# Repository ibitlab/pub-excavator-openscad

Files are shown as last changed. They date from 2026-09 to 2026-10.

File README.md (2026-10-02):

**English** · [Українська](README.uk.md)

<picture>
  <source media="(prefers-color-scheme: dark)" srcset="docs/logo/ibitlab-logo-dark.svg">
  ibitlab
</picture>

# Mini excavator boom, stick and bucket — a parametric OpenSCAD model

> ⚠️ **Ihor Ivaniuk (@IBITLAB) is the originator and product owner: organises the AI's work, sets the tasks, makes the decisions. The execution — geometry, calculations, drawings, code and texts — is done by AI (Claude Code by Anthropic).** Not checked by an engineer, never built, never tested. A mini excavator can maim and kill; everything here is provided as is, at your own risk. The full disclaimer is [below](#disclaimer); the hazards specific to this design are in [SAFETY.md](SAFETY.md). Read both before you cut any metal.

## ▶ [Open the live 3D model](https://ibitlab.github.io/pub-excavator-openscad/)

**[ibitlab.github.io/pub-excavator-openscad](https://ibitlab.github.io/pub-excavator-openscad/)** — nothing to install: OpenSCAD runs inside the page (WebAssembly). Move the boom, stick and bucket or simply drag the bucket with the mouse, switch on the work envelope and the "what is welded to what" colouring, change any parameter of the model — it is rebuilt right in the browser. Works on a phone too.

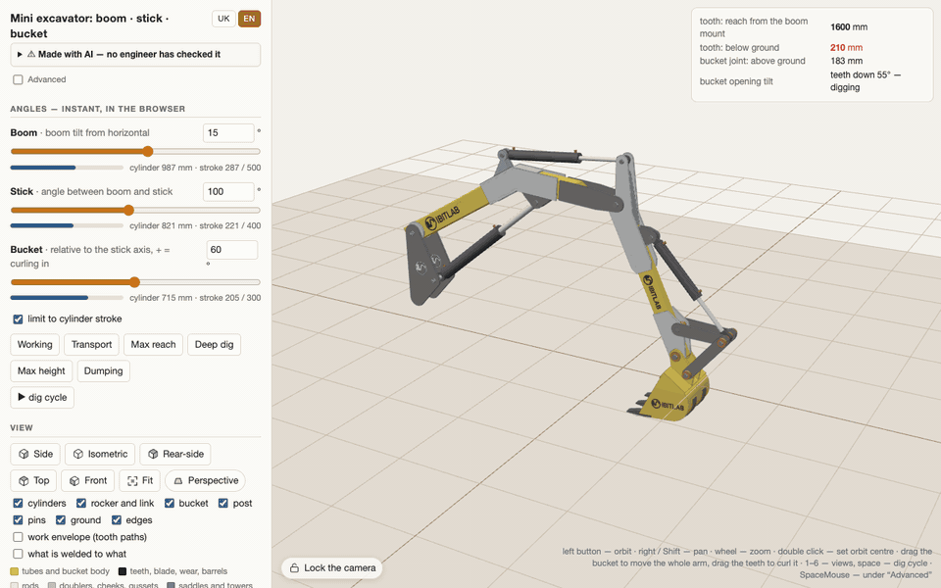
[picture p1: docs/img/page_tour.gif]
A tour of the 3D page: the dig cycle, the work envelope, the extreme poses, what is welded to what (https://ibitlab.github.io/pub-excavator-openscad/)


**AR at 1:1.** On an Android phone with Chrome the same page puts the machine on the ground through the camera, at full size; the sliders move the boom, stick and bucket exactly as on screen (clip sped up 4×). How it works: [web/README.md](web/README.md).

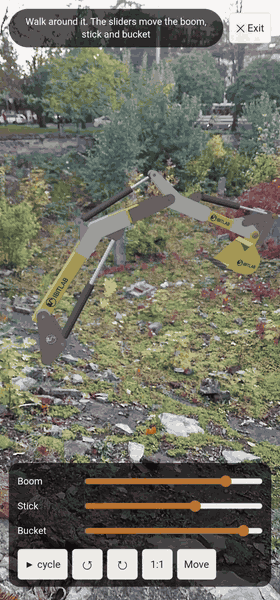
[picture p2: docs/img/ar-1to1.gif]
The excavator in AR at 1:1 on a patch of ground, sliders moving the boom, stick and bucket


## Documents (PDF, in Ukrainian)

**[Part sketches in steel](latest/drawings/parts.pdf)** — the bill of materials, every plate with its hole positions tied to real edges, the tubes unfolded on all four sides; the logo is marked where the decal goes. For cutting: DXF 1:1 in [`dxf/`](latest/dxf/).

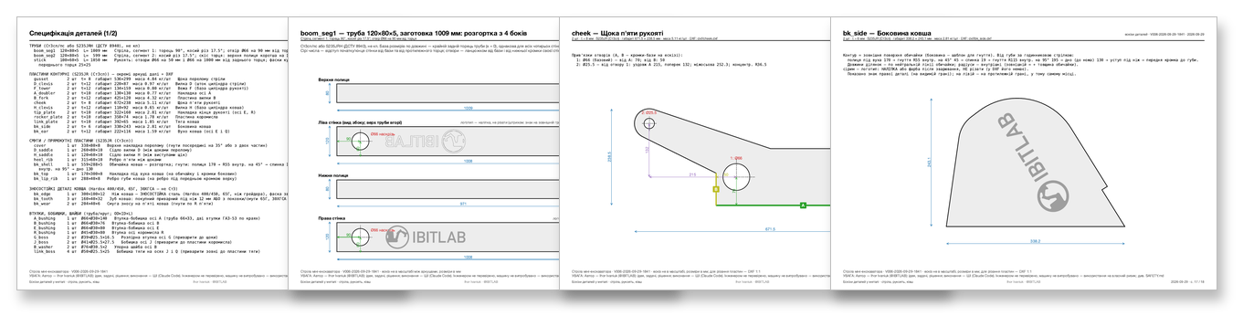
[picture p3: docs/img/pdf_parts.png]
Part sketches in steel


**[1:1 sorting sheets for the 1:5 printed kit](latest/print3d/sheets/SHEETS.pdf)** — every printed part drawn at 1:1 the way it lies on the table: put the part on its outline, and if it fits, that is the one; renders of each sub-assembly with a callout to every file, then gluing step cards.

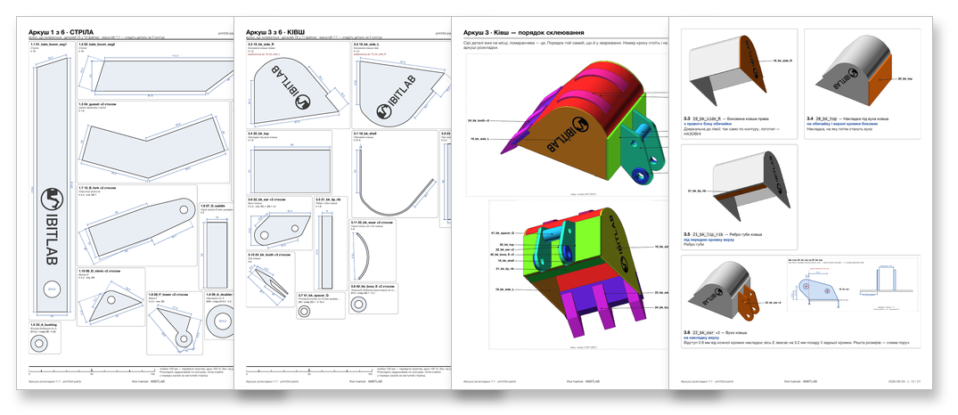
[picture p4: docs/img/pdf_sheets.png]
1:1 sorting sheets for the 1:5 printed kit


> 📘 **All the technical detail is in [TECHNICAL.md](docs/TECHNICAL.md)** — how to run the model, the chosen geometry and kinematics, the bucket, sections and steel, the AI review, **what must be checked before cutting metal**, fabrication notes and the next stages. Installing and the core commands: [QUICKSTART.md](docs/QUICKSTART.md). How the code is built — the files and scripts, the stack, links between parts, data formats: [ARCHITECTURE.md](docs/ARCHITECTURE.md); the 3D pages — phones, AR, the SpaceMouse: [web/README.md](web/README.md); geometry in the pages, print versus steel, the OFF format: [GEOMETRY.md](docs/GEOMETRY.md).

## What this is

Working equipment (boom + stick + bucket linkage + a **300 mm bucket**) built around **already-purchased** hydraulic cylinders:
boom ГЦ 63.40.500.700 (ШС-30 spherical bearing), stick ЦС50.25.400.600 (ШС-25), bucket ЦС50.25.300.510 (ШС-25).
The arms are made of common hollow sections (ordinary stockist sizes); the reinforcements are doublers, cheeks and saddles in S235JR (Ст3) steel.
The bucket is welded up from real parts (side plates, shell, cutting edge, teeth, ears) and checked for collisions with the stick, the rocker and the link over the full cylinder stroke.

| At a glance | |
|---|---|
| Max digging reach / at ground level | 2.90 m / 2.83 m |
| Max digging depth | 1.72 m |
| Max dumping height | 2.55 m |
| Bucket | 300 mm wide, 16.4 l struck / 21.3 l heaped |
| Force at the tooth (bucket cylinder, 160 bar) | up to 11.8 kN |
| Steel without the cylinders and the column | ≈ 130 kg |

*Computed from the model (version V005) with pin A 650 mm above the ground; the working-range drawing and every number behind it are in [TECHNICAL.md](docs/TECHNICAL.md), section 3.*

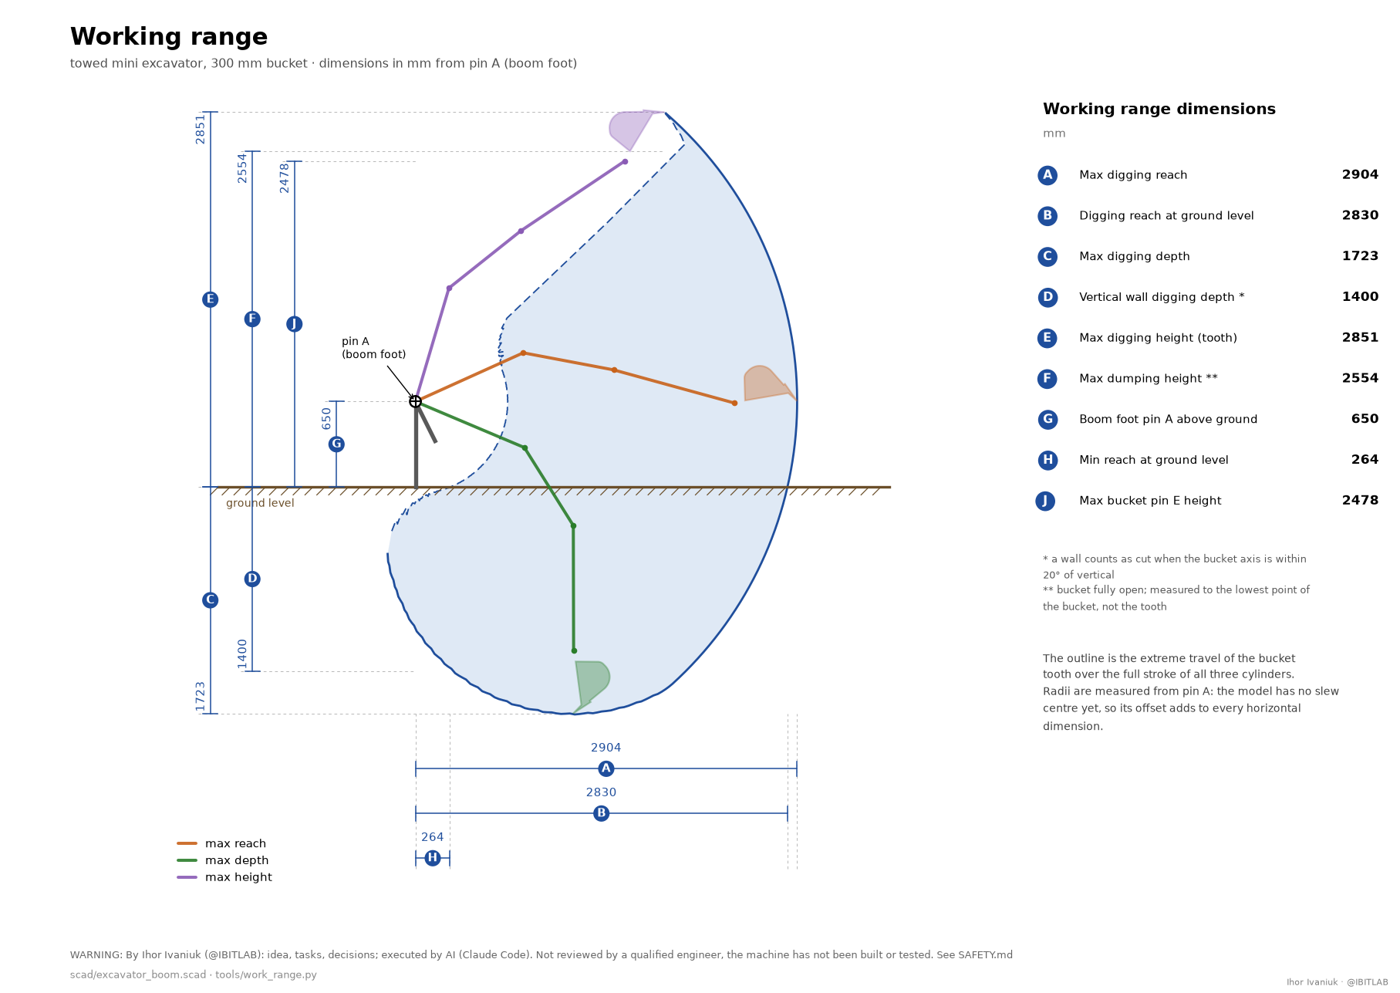
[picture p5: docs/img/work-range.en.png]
working range


## The 1:5 printed kit

Every component can be printed at 1:5 and glued together exactly where it would be welded in steel: 54 files, 76 pieces. The 1:1 sorting sheets above are made for gluing it; how the kit is split up and printed is in [print3d-parts/README.md](print3d-parts/README.md).

Printed, not glued together yet:

| Cylinders | Plates and a tube on the build plate | Logo plates |
| --- | --- | --- |
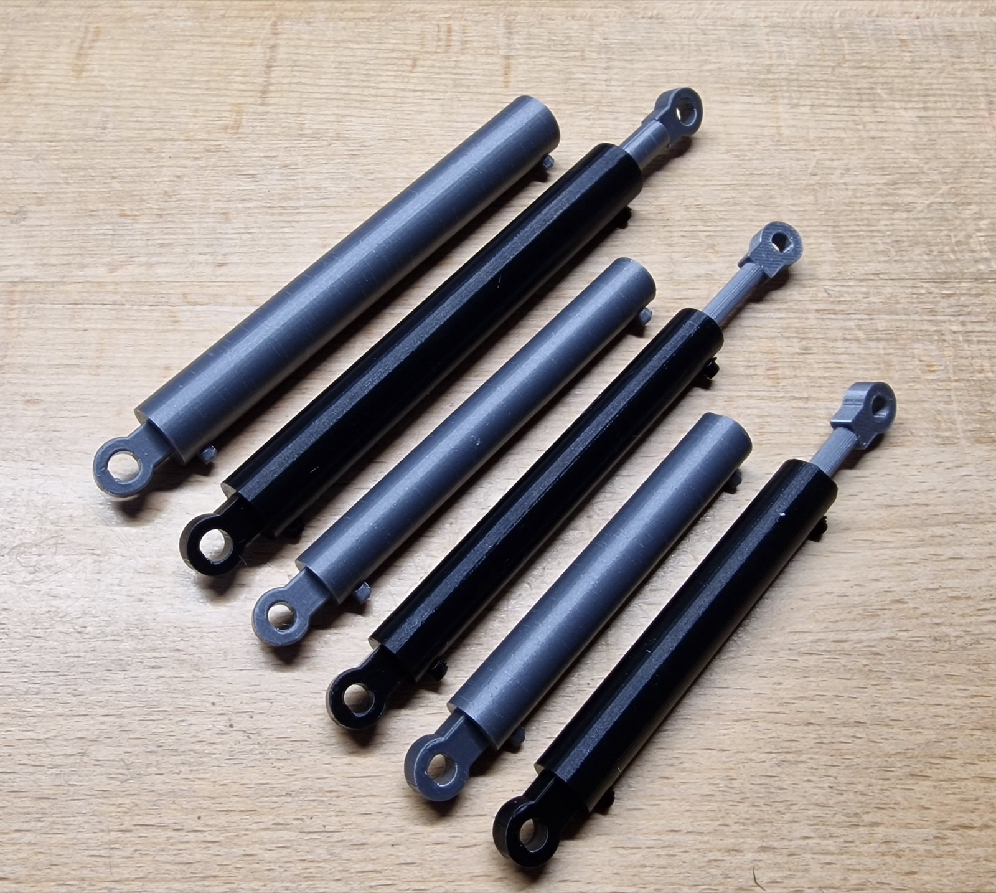
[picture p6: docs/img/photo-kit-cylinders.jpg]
The hydraulic cylinders of the 1:5 kit, printed
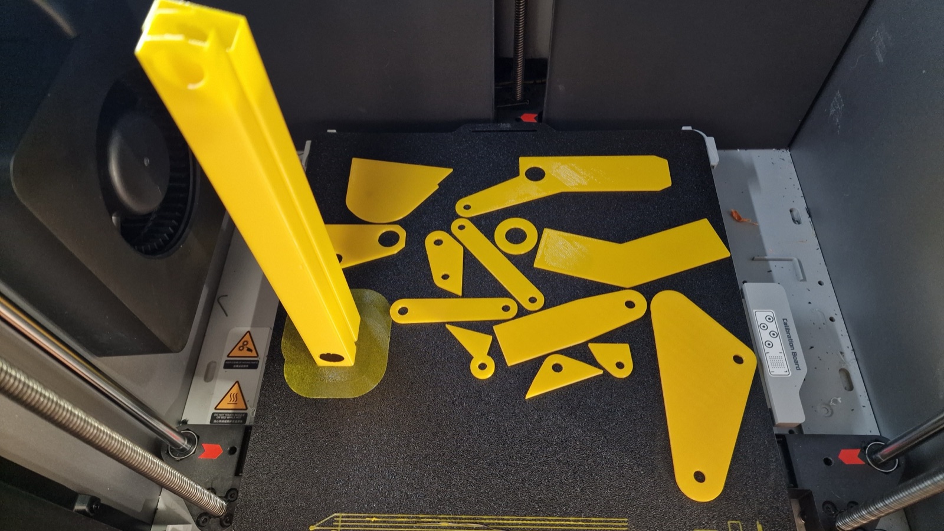
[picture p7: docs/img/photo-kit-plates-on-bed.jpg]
Yellow plates and the stick tube on the build plate
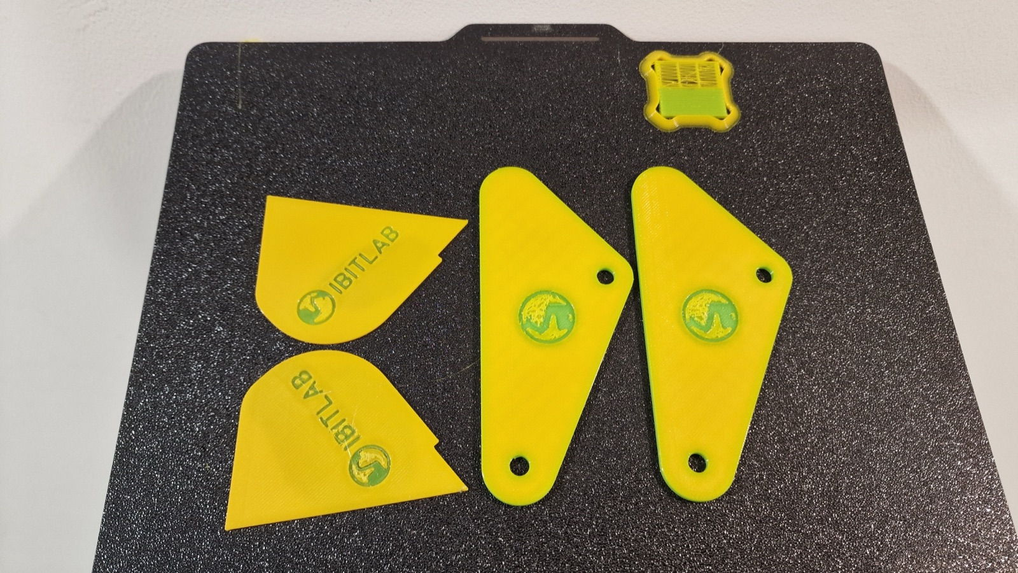
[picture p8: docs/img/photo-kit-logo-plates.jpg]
Plates with the logo where the decal goes
|  |  |  |

## How this was made

**Ihor Ivaniuk (@IBITLAB)** is the originator and the product owner. From the author: the idea of the machine (a towable mini excavator built around hydraulic cylinders already bought), every task, the choice of what is kept and what is rejected, the review of the results — on the renders, on the 3D page, on the printed kit held in hand — and the organisation of the AI's work itself: which checks must exist, what every document has to look like, what gets published. This is a lot of hours of work, spread over many sessions. How it started, in the author's own words and with the first prompts: [STORY.md](docs/STORY.md).

**The AI does the execution** — Claude Code by Anthropic: the OpenSCAD model and its independent Python twins (kinematics, strength, the bucket), the drawings, the bill of materials and the DXF files, both 3D pages, the 1:5 printed kit with its sorting sheets, and the texts in both languages. The "independent reviews" are also done by AI agents with different lenses; their findings go to the author, who decides what to fix.

**Tools:** OpenSCAD (Manifold engine) · Python (numpy, shapely, matplotlib, Pillow) · three.js · OpenSCAD compiled to WebAssembly + Vite · headless Chrome (page checks, PDFs) · poppler · ffmpeg.

None of this has been checked by a qualified engineer — see the disclaimer below.

## Disclaimer

> ## ⚠️ Made with AI. Use at your own risk
>
> **The idea, the tasks and the decisions are the author's (Ihor Ivaniuk); all of this documentation, the model geometry, the calculations, the drawings and the bill of materials were produced and computed by artificial intelligence (Claude Code) to those tasks.** None of it has been checked or approved by a qualified engineer. The "independent review" in section 4a of [TECHNICAL.md](docs/TECHNICAL.md) was likewise carried out by AI agents, not by human experts.
>
> This is **not engineering documentation**. The calculations are simplified, the inputs are incomplete (some were taken from vendor pages marked "≈"), and nothing has been tested physically — no machine has ever been built from this model.
>
> **A mini excavator is a dangerous machine.** A weld that lets go, a pin that shears, a boom that drops under load, a tip-over, a burst hose, a pinhole jet of hydraulic oil (it injects under the skin and requires immediate surgery) — these maim and kill.
>
> **The author and any contributors accept no liability whatsoever** for the consequences of using this material: for harm to life or health, injury, death, damage to property, direct or indirect losses, or for errors in the calculations, drawings or descriptions. The material is provided "as is", without warranty of any kind, express or implied, including any warranty of fitness for a particular purpose.
>
> **Whatever you do with this material, you do at your own risk and on your own responsibility.** Before cutting metal, have the calculations and drawings checked by a qualified mechanical engineer, have the welding done by a certified welder and the hydraulics by a specialist. Follow your local safety regulations. The machine is not certified and is not intended for sale, for commercial use, or for use on public roads.
>
> 👉 **The specific unfinished points and hazards of this particular design are in [SAFETY.md](SAFETY.md). Read it before you cut anything.**

## Licence

**No licence has been chosen for this project yet**, so what was authored here is "all rights reserved" for the time being. This is deliberate: a licence can be added later, but one that has been granted cannot be withdrawn. The output of OpenSCAD (STL, DXF, sketches, BOM) belongs to the project either way: OpenSCAD's own GPL does not reach its output, and this model includes no external SCAD library.

Separately: the `web/viewer-wasm/dist/` build **embeds OpenSCAD itself under GPL-2.0** ([web/viewer-wasm/LICENSE](web/viewer-wasm/LICENSE)). The engine comes from `openscad-wasm-prebuilt@1.2.0`, which ships the GPL text and names its source, so the terms can be met: when you publish `dist/`, put `web/viewer-wasm/LICENSE` and [THIRD-PARTY.md](THIRD-PARTY.md) next to it — that file lists every third-party component and points at the engine sources.

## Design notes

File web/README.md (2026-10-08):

**English** · [Українська](README.uk.md)

# The 3D pages

> ⚠️ **By Ihor Ivaniuk (@IBITLAB): idea, tasks, decisions; executed by AI (Claude Code).** Not checked by an engineer, never built, never tested. The full disclaimer is in [README.md](../README.md#disclaimer).

Two versions of one interactive page for the model `scad/excavator_boom.scad`: orbit the machine, move the boom, stick and bucket, rebuild it with any other parameter. The live one is published on GitHub Pages.

| Page | Start | Rebuild after a parameter change | What it needs |
|---|---|---|---|
| With a server | `web/viewer.sh` → `viewer.py` + `viewer/index.html` | ≈ 0.4 s (desktop OpenSCAD) | Python and OpenSCAD; Ukrainian only |
| No backend | `web/viewer-wasm.sh` → `viewer-wasm/` (Vite) | ≈ 2.2 s (OpenSCAD-WASM in the browser) | Node to build; two languages, phones, AR |

The rest of the technical detail is in [docs/TECHNICAL.md](../docs/TECHNICAL.md); how the pages get their data (the `VIEW` echo, the OFF meshes, the shared code blocks) is in [docs/ARCHITECTURE.md](../docs/ARCHITECTURE.md) and [docs/GEOMETRY.md](../docs/GEOMETRY.md).

## 1. The page with a server (`web/viewer/`)

```
web/viewer.sh                                   # opens http://127.0.0.1:8765/ in the browser (Ctrl+C to stop)
python3 web/viewer.py --export file.html        # a static page with no server (one ships with every version: latest/viewer.html)
```

- **Mouse**: left button orbits, right button or Shift pans, the wheel zooms towards the cursor, a double click on a part sets a new orbit centre. There are view buttons (side, isometric, top, front, fit) and a perspective / orthographic toggle.
- **The boom, stick and bucket angles** move the model instantly: the page assembles the pose itself, using the same formulas as the model's `pt_*()` functions and the points the model prints in `echo(VIEW = …)` (cross-checked against the model's echo: the tooth position and the cylinder lengths agree to within 0.1 mm). The slider limits come from the cylinder strokes; next to each angle you see the cylinder length and the stroke used. Clear "limit to cylinder stroke" and a cylinder beyond its stroke turns red. Ready-made poses and a "dig cycle" are included.
- **Every other parameter** (the Customizer groups are read straight from the `.scad` — there is no separate list) goes to a local server: it runs OpenSCAD in parallel for 12 parts in their own coordinate frames and returns coloured meshes (OFF format). Changed parameters are highlighted; "Copy changes" gives you lines ready to paste into the `.scad`; "Reload model" picks up edits to the file. Warnings from the model (`!!!` — a dead centre in the linkage, an unreachable cylinder length) are shown on screen.
- The server listens on 127.0.0.1 only; values coming from the browser are coerced to the types in the schema (numbers, booleans, enumerations), so arbitrary text never reaches OpenSCAD. three.js is loaded from a CDN (jsdelivr) — an internet connection is required.

## 2. The page with no backend: OpenSCAD-WASM in the browser (`web/viewer-wasm/`)

```
cd web/viewer-wasm && npm install      # dependencies: three, openscad-wasm-prebuilt (OpenSCAD 2025.01 + Manifold, 11 MB), vite
npm run dev                              # http://localhost:8766/ — editing scad/excavator_boom.scad reloads the page at once
npm run build                            # a static site in dist/ (≈12 MB): drop it on any static host
npm run preview                          # view the built dist/ locally
npm test                                 # a smoke test with no browser
# the same in one command from the repository root: web/viewer-wasm.sh [build|preview|phone|test]
# phone — build and serve it to your phone on the same Wi-Fi (Vite otherwise listens on 127.0.0.1 only)
```

- The same page and the same controls as the server version (which is still there: `web/viewer.sh`), except that **OpenSCAD runs in a web worker in the browser**; neither Python nor an installed OpenSCAD is needed. The model is embedded into the page at build time (a `?raw` import) and the Customizer parameters are parsed by JavaScript (`src/schema.js`).
- One engine run per parameter change: in `part="view_all"` mode the model lays all 12 parts out with an offset along Y and the page cuts the mesh back apart (`src/offmesh.js`). Measured in Chrome: the first start takes ≈ 5 s (loading the engine), a **rebuild after a parameter change ≈ 2.2 s**; the angles remain instant. For comparison, the server version rebuilds in ≈ 0.4 s.
- **Two languages: English and Ukrainian.** A `UK | EN` switch sits in the panel header; the language comes from `?lang=en` in the URL, then from the browser's storage, then from the browser's own language. Switching only redraws the labels — OpenSCAD is not restarted, and the angles, checkboxes and changed parameters all stay as they were. The group names and the descriptions of all 103 model parameters are translated too: the English texts live in `src/i18n.js` while the Ukrainian ones are read straight from the `.scad` comments, so the model remains the single source of truth. `npm test` verifies that the dictionary has not drifted from the model (every group and every documented parameter has a translation) and that both languages carry the same keys. Warnings printed by the model itself (`!!!`) stay in Ukrainian — they come from `echo()` in the `.scad`. The server page (`web/viewer.sh`) is Ukrainian only.
- **The page reads only the language from the URL** (`?lang=en`). Initial parameter values used to be given there too — that was removed on purpose: it was the one path by which a value from someone else's link reached the text of the OpenSCAD model. The model is embedded into the page at build time, and **there is no way to open somebody else's `.scad` in it either** — that was removed on purpose: such a file's text would become the group names, descriptions and warnings in the panel, i.e. foreign data inside a page that lives on a shared GitHub Pages domain.
- **On phones and tablets the panel is a bottom drawer** with three states: collapsed (just the grab bar with the reach and the tooth height — the model gets 93 % of the screen), working (the three angle sliders and the ready-made poses) and full (the view presets and visibility checkboxes as well). Drag it by the handle, tap the handle to collapse or expand. The layout is triggered not only by width but by `pointer: coarse`: a phone held sideways (844 px) and a tablet in portrait (768 px) would otherwise get a side column taking half the screen. Model parameters, devices and the render views are hidden on touch devices — nobody edits those from a phone. The AI warning is collapsed by default **everywhere** — only the summary line shows and the reader opens the rest themselves; on a phone it sits behind a ⚠ icon on the handle, next to the collapse button and the language switch, and opens as a card over the model. The handle sticks to the top of the panel, so you can collapse and expand from anywhere in the scroll — and the scroll position is kept. A note at the bottom of the panel says what the phone version leaves out. On a phone the view presets sit as **icons in the "Angles" heading row** — an isometric cube with the face you are looking at shaded, the way CAD tools do it. The whole set then fits on the first screen without a block of its own; on a desktop the label stays next to the icon. The projection is a state rather than a view, so it sits in a group of its own behind a divider, is round instead of rectangular, and its icon shows the current state: the frame converges in perspective and stays parallel in orthographic.
- **Snapshot of the frame.** The "⤓ Save PNG" button in the "View" section gives you the current frame together with a caption strip: the tooth's reach, its depth below or height above the ground, the boom, stick and bucket angles, the bucket tilt and the height of axis A above the ground that all of it is measured from. A screenshot cannot do this — it drags the whole panel along and leaves the numbers tiny. On a phone the button opens the system share sheet, so the picture goes straight into the photo library or a message.
- **A colour legend** under the visibility checkboxes: tubes, plates and doublers, hydraulic cylinders, bucket, bushings and pins. The colours are not invented — they are taken from the `color(...)` calls in the model itself, and `npm test` checks that they have not drifted apart.
- **"What is welded to what"** — a checkbox that repaints the machine by RIGID BODY: the boom in one colour, the stick in another, then the bucket, the rocker, the link, the barrels and the rods, with the pins in bright red. The same colour then means "welded into one piece", a colour boundary is a joint, and a red dot is the axis it turns about. The normal palette says what a part is MADE OF; this one says WHAT MOVES relative to what — different questions, hence different modes. The colours were not picked by eye: ΔE was measured in CIE Lab on the eleven pairs that actually touch at joints, and the minimum is 30.
- **Tapping a part highlights everything welded to it** and fades the rest of the machine. "What moves together with this?" is answered in one tap, with no mode to switch. Tapping it again, or tapping empty space, clears the highlight; dragging the bucket leaves it alone.
- **An engine loading bar.** The 11 MB used to arrive in silence, which on a slow link looked like a hang. The page now fetches the file itself, as a stream, and shows "4.2 / 11 MB" — exactly once, with no double download. The tooth's depth below ground is highlighted in the HUD: it is the page's headline number.
- **Keyboard (where there is one):** `1`–`6` for the view presets, space for the dig cycle. On touch devices the handlers are not installed at all.
- **AR at full size (WebXR).** On an Android phone with Chrome (ARCore services required) a "◎ AR 1:1" button appears in the corner above the model. The machine is placed on the floor through the camera: the ring is the point on the ground under axis A (the boom foot), the axis sits at the "axis A above ground" height, and the boom points to the right, so you see the machine from the side. That is how you put it on the edge of a pit and "dig" into it; ↺ ↻ turn it about axis A. The scale is real (ARCore measures space metrically, to within a few per cent), you can walk around it, and the three sliders and "▶ cycle" move the boom, stick and bucket exactly as on screen: the same code computes the pose, OpenSCAD is not rerun. Scale 1:1 (outdoors) or 1:5 (on a table), 15° turns, "Move" puts it somewhere else. Where the browser cannot do AR (a computer; an iPhone — Safari has no WebXR for AR) there is no button. It needs https (GitHub Pages) or localhost; the address from `web/viewer-wasm.sh phone` is plain http over Wi-Fi, so before publishing, in Chrome on the phone: `chrome://flags/#unsafely-treat-insecure-origin-as-secure` → enter the address the script prints (`http://COMPUTER-ADDRESS:8767`) → Enabled → Relaunch; set it back to Default after testing. Port forwarding over a cable (`chrome://inspect` → Port forwarding) never shows the debugging permission prompt on some phones — the flag needs neither a cable nor extra software. Without a real phone only the logic can be checked: `probe.mjs --pre` with a stub `navigator.xr` (the button, the session request, the refusal message) and `__ARUI__()` — the overlay without a session.
- **AR: the room — occlusion, planes, mesh, collisions.** The session asks for three optional WebXR features. Each one is used only where the browser grants it, and a small line under the hint shows which ones it got ("depth ✓ · planes — · mesh —"). **Depth** (`depth-sensing`, Chrome on Android with ARCore Depth, which covers most current phones): real objects hide the machine, so the boom goes behind a post instead of being drawn over it. The ◐ button turns it on and off. **Planes** (`plane-detection`; in Chrome on Android behind the `chrome://flags/#webxr-incubations` flag, on Quest from the room scan) and the **room mesh** (`mesh-detection`, Quest 3; Chrome on Android does not provide it) are drawn semi-transparent: walls blue, horizontal surfaces green, objects orange. The ▦ button hides them, and collisions are still checked while they are hidden. **Collisions** are checked ten times a second. Each body of the machine contributes up to 120 of its vertices, and it counts as a collision if the segment from the body's hinge (A, B, E, cylinder pins) to a vertex crosses a wall, ceiling, table or object, or if the vertex comes within 3 cm of one. The body then turns red, red balls mark the contact points (visible even without the overlay), a "⚠ Collision: wall — boom" banner appears at the top and the phone gives a short buzz. The ⚠ button turns collision checking off (and clears the marks) when you want to see the machine pass through a wall on purpose; the room keeps being tracked, so turning it back on works at once. The floor the machine stands on is ignored, since the bucket is meant to dig below it. The vertices are a sample, so a thin object between them (a chair leg) can slip through. **Room snapshot** (`src/keep.js`). ARCore merges neighbouring planes and drops planes the camera has turned away from, which for collisions would mean the wall is gone. So a plane that disappears stays as a ghost with a dashed outline. If a live plane covers it again (the same plane, at least 60 % inside), that is a merge or a reappearance: the ghost goes, and the live plane counts one more confirmation. If nothing covers it within 5 s, a plane that has already reappeared once, or a large one (≥ 1 m²) seen for 5 s or longer, stays until the end of the session with a solid fill. Anything else is treated as noise and removed. A kept plane is dropped only if the depth map shows six times in a row (1.5 s) that the camera sees at least 25 cm further through it. Ghosts take part in the collision check. The line under the hint shows "kept N, pending M". The snapshot lives only for one session: the space of the next session starts from a different point. **Room scan** (the ▤ button, `src/scan.js`, off by default). While the button is on, the depth frames merge into one 3D model of the room. Each depth point is tied to the session space by the camera pose that ARCore tracking gives for that frame, the same tracking that stands the machine on the floor, so the planes are not needed for this. The method is the one KinectFusion uses: a sparse grid of 5 cm voxels (8×8×8 blocks created only where a surface was seen). Each voxel stores the truncated signed distance to the surface (±15 cm) and a weight. Four times a second a frame of 96 rays along its long side is added as a weighted average, so the noise of single frames averages out. Along half of the rays the space in front of the surface is cleared, so a person who walked through disappears from the model. Once a second the changed blocks are remeshed with Surface Nets. The model is split into 1.6 m chunks, and only the chunks that changed are rebuilt. It is drawn as a fill with a wireframe, coloured like the room by slope. Volume is conveyed four ways, all computed from the same distance field. Smooth normals come from its gradient, so there is no "rippling" of the faces. Ambient occlusion darkens hollows: a step along the normal that meets another surface sooner than expected means a hollow, such as the corner of a wall and the floor or under a table (about 12 cm, the field knows nothing further out). Surfaces turned sideways to the view are darker, as if a lamp were mounted on the camera. Far surfaces are slightly dimmer. The last two act only on the scan, not on the machine. The "Scan" slider in the panel sets its opacity. The range runs from barely visible to solid, and a solid model hides the camera image: you see only the model, and reality shows through only where nothing has been scanned yet. Pressing ▤ again pauses the scan, and the model stays until the session ends. The line under the hint shows "scan N k △". Memory is capped at 20,000 blocks, about 50 MB for the voxels. A room of 4 × 5 m takes about 850 blocks, so this is enough for twenty such rooms. The limit is there only so that a very long scan does not eat all the memory of the tab. The scan does not take part in collisions yet. The limits: depth is reliable only up to 4 m, and if tracking drifts the model shifts with it. On a headset without the overlay (Quest), the trigger places the machine and later puts it back into place-finding mode, and the grip button starts the dig cycle. The collision geometry lives in `src/room.js`, with no DOM, and `npm test` checks it with numbers. `__ARSCAN__(z)` scans a synthetic box room from 16 depth frames (all vertices must lie within 3 cm of its walls) and runs the snapshot for a wall at `z` (−3: kept; −2: the depth map removes it). `__ARSIM__(x)` puts the real 1:1 model in front of a wall x m away and returns the bodies that hit it (a wall at 1 m: the boom and the stick cylinder; at 6 m: nothing). Occlusion, planes and the mesh can only be checked on a real device.
- **The machine can be dragged by the bucket.** Grab the bucket body and the whole arm follows your finger: the page solves the inverse kinematics and works out the boom and stick angles. Grab the teeth and the bucket curls about its own axis while the arm stays put. Works with a mouse and with a single finger. The solution is exact and needs no iteration — joint B lies on the intersection of two circles — and `npm test` runs the forward problem through the inverse one and back (tooth error 10⁻¹² mm). An unreachable target does not freeze the arm: it follows to the edge of the working envelope, and the cylinder-stroke limit still applies. The "Lock the camera" toggle disables orbiting altogether, so you can then drag from anywhere without aiming at the bucket. On a phone it sits on the drawer handle next to the ⚠ icon — the handle is sticky and always visible, whereas the view row in the heading scrolls away. On a desktop it floats over the canvas in the bottom-left corner, next to the thing it governs. Locked, it turns orange. How to control it is written in the card behind the ⚠ icon, next to the AI warning — it lives there **permanently**, on the phone and on the desktop alike. On top of that, a first-time visitor gets the same text as a pill above the model: it stays until they have completed **two** operations (after one it is not yet clear the gesture repeats) and closes on the ×. After that the text stays behind the icon.
- **Publishing to GitHub Pages**: `.github/workflows/pages.yml` builds the page and deploys it on every push to `main` (enable it once: Settings → Pages → Source: GitHub Actions). The workflow runs `npm test` before building, so a broken model never reaches the site, and it copies `LICENSE` and `THIRD-PARTY.md` next to the page — the GPL requires this, because the page embeds OpenSCAD itself. The same links appear at the bottom of the page's panel.
- **Link preview card**: the Open Graph tags in the `<head>` of `index.html` (English title and description) and `public/og.png` (1200×627, the isometric render) make LinkedIn, Facebook and messengers show a card with a picture. The URLs there are absolute, so they change if the site moves. After a change, LinkedIn keeps the old card until the address is re-read in its Post Inspector.
- `dist/` cannot be opened by double-clicking (a page opened as a local file cannot start module workers) — you need any static web server (`npm run preview`, GitHub Pages and so on). `node_modules/` and `dist/` never reach git.
- The in-browser engine is older (2025.01) than the desktop OpenSCAD (2026.09). `npm test` checks that it builds the model without warnings, that no part comes out empty, that the JavaScript pose matches the model's echo, and that the pose block is identical in both versions of the page.

### Colours in AR

| What you see | What it means |
|---|---|
| White ring | Where the machine will stand. Shown while a place is being found; a tap places the machine there |
| Blue, see-through | A wall: a vertical plane, a wall in the room mesh, or a vertical part of the scan |
| Green, see-through | A horizontal surface: floor, table, ceiling |
| Orange, see-through | Everything else: objects in the room mesh, sloped parts of the scan |
| Dashed outline, faint fill | A plane the browser has lost. It waits up to 5 s for a decision (snapshot) |
| Dashed outline, normal fill | A lost plane kept until the end of the session |
| Fill with a wireframe (▤) | The room scan. Same colours, by slope; the "Scan" slider sets its opacity |
| Red balls, reddish body | Collision points and the part of the machine that hit something |
| Red banner at the top | The collision warning: what was hit and by which part |

## 3. A 3Dconnexion SpaceMouse in the browser

Both pages (server and WASM) can be driven with a 3D mouse without any plugin; the block of code is identical in both (`spacemouse`).

| Browser | Route | What to do |
|---|---|---|
| **Chrome / Edge / Opera** | WebHID — the page reads the mouse reports itself | "View" → the **SpaceMouse** button → in the browser dialog ("… wants to connect to a HID device") pick the mouse (or "3Dconnexion Universal Receiver") → "Connect". The dialog only appears after a click — that is a browser requirement. Permission is granted **per origin** (`127.0.0.1:8765`, `localhost:8766`, `localhost:8767` are three different ones) and lasts as long as the mouse is on and the browser is open; if the mouse reports a serial number, Chrome remembers the permission for good and the page picks the mouse up by itself (including after it is plugged back in). If not, the button has to be pressed again after a browser restart. To revoke: the icon to the left of the address → "Site settings" → HID devices. A secure context is required: https, `localhost` or a local file (verified: Chrome opens WebHID for a static `viewer.html` from disk too). |
| **Firefox** | The Gamepad API (Firefox has no WebHID) — the mouse appears as a 6-axis "gamepad" | Nothing to press: **nudge the cap or press a mouse button** while the tab has focus and the status changes to "connected (Gamepad API)". To check whether Firefox sees the mouse at all: `about:support`, or any "gamepad tester". The same route also works in Chrome as a fallback. |
| Safari | — | neither WebHID nor access to a 3D mouse through the Gamepad API |

- **Controls** ("object in hand" mode): the cap right/left and up/down pans; pushing and pulling zooms; twisting rotates about the vertical; tilting towards and away from you raises the camera. Button 1 is "Fit", button 2 steps to the next standard view. The sensitivity slider and the three inversion checkboxes (pan / zoom / rotate) are remembered in the browser. Roll (tilting sideways) is deliberately unused: the model's vertical stays vertical.
- **The bucket on the mouse (WASM page only)**: with "Lock the camera" on, the mouse no longer moves the camera but drives the **bucket**. The operator controls the bucket itself; the boom, stick and bucket work out their motion together, so the bucket travels without turning (`armFromBucket` in `src/ik.js`, an exact solution with no iteration). Push / pull moves the tooth straight forward / back, press / lift moves it down / up, tilting forward curls the bucket in (teeth up towards you) and tilting back dumps it: the bucket turns about pin E while the boom stays put. A switch under "Devices" sets the reference frame: **from the base** is an operator standing at axis A looking along the boom, so left / right, twist and roll do nothing (the swing column is not designed yet); **from the camera** lines the cap axes up with the screen, and whatever goes into the screen or sideways off the machine's plane is dropped. A cylinder reaching its end stop does not stop the bucket outright: it first keeps its angle to the stick, then slides along the stop, only horizontally or only vertically. The bucket does not jump over a point it cannot reach; it stops short of it.
- **macOS:** if the 3Dconnexion driver is installed, `3DconnexionHelper` opens the mouse exclusively (in `ioreg` the Chrome client shows `ClientSeized = Yes`), so the SpaceMouse button fails with "Failed to open the device". The fix: `tools/dev/spacemouse-driver.sh off` → press the button again → in the dialog pick **your actual mouse** (the "3Dconnexion Virtual Mouse / Virtual Data" entries are the driver's virtual devices, not it). To restore the driver for CAD applications: `tools/dev/spacemouse-driver.sh on` (it starts by itself after you log in). **Automatically:** `tools/dev/with-spacemouse.sh <command>` releases the helper before the start and restores it as soon as the command ends for any reason (Ctrl+C, closing the terminal, an error) — `tools/dev/with-spacemouse.sh web/viewer.sh`, and for the WASM page `npm run dev:sm` / `npm run preview:sm`. If the helper was not running to begin with, it is not started either. Plain `npm run dev` / `preview` leave the driver alone.
- **The 3DxWare driver** can get in the way: on Windows and macOS it sends scrolling and key presses into the browser window itself (movement appears "doubled") or holds the device. If that happens, disable the mouse for the browser in 3Dconnexion Home, or close the driver while you work with the page. For Firefox on Windows/macOS the driver usually **has to** be closed, otherwise the "gamepad" never appears.
- **Linux**: Chrome/WebHID needs access to `/dev/hidraw*` — a udev rule `SUBSYSTEM=="hidraw", ATTRS{idVendor}=="256f", MODE="0660", TAG+="uaccess"`; Firefox takes the mouse through `/dev/input/js*` with no configuration (spacenavd is not needed and must be off if it grabs the device).
- **What has been verified**: the navigation logic, automatically, in headless Chrome with mock devices of both kinds (`web/viewer-wasm/test/spacemouse.mjs`: reports 1/2/3, the 12-byte report of newer models, the buttons, the Gamepad API, the bucket with the camera locked in both reference frames). **It has never been tried with a real mouse** (there was none during development): if some axis goes the wrong way, turn on the matching inversion; if the mouse does not respond at all in Chrome, open `chrome://device-log` and see whether HID reports arrive.
- The official 3Dconnexion route (the "3DxWare for Web" SDK, a WebSocket to the driver — the way Onshape works) is not used here: it requires an installed driver and a licensed SDK, but it does work identically in every browser. If WebHID/Gamepad turn out not to be enough, that is the next option.

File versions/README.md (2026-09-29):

# versions/ — archive · архів

**English.** The current build is always in [`../latest/`](../latest/). A version lands here, under its own name, only when a newer build changes the geometry or the report numbers: `tools/build_version.sh` moves the old `latest/` here with `git mv`, the 1:5 printed kit and its sub-versions included. Cosmetic rebuilds (colours, renders, PDF style) refresh `latest/` in place instead.

V002–V005 are not in the tree: their STL and DXF were byte-identical to V001, and the only change in the numbers (the tooth reach, 2890 → 2904 mm) is carried by every later version. They stay in git as tags — `git checkout V004`, for example. V001 is kept as the starting point.

**Українською.** Поточне збирання завжди в [`../latest/`](../latest/). Версія потрапляє сюди, під своєю назвою, лише коли новіше збирання змінило геометрію чи числа звітів: `tools/build_version.sh` переносить старий `latest/` сюди через `git mv` — разом із друкованим набором 1:5 і його підверсіями. Косметичні перезбирання (кольори, рендери, стиль PDF) оновлюють `latest/` на місці.

V002–V005 у дереві немає: їхні STL і DXF були байт-у-байт такі самі, як у V001, а єдина зміна в числах (виліт зуба, 2890 → 2904 мм) є в кожній пізнішій версії. У git вони лишаються тегами — наприклад, `git checkout V004`. V001 збережено як точку відліку.

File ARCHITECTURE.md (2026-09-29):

**English** · [Українська](ARCHITECTURE.uk.md)

# Software architecture

A short map: what the code is made of, who calls whom and in what format the data moves. Engineering detail is in [TECHNICAL.md](TECHNICAL.md); geometry in the pages, print versus steel and the OFF format are in [GEOMETRY.md](GEOMETRY.md).

## 1. Principle

- **One source of truth** — `scad/excavator_boom.scad`. Everything else consumes it.
- **The model's interface is the OpenSCAD command line**: input is `-D name=value`, output is a geometry file plus `ECHO:` lines on stderr. No tool keeps its own list of dimensions: numbers are read from echo, outlines from the export.
- **Twins** (`tools/kinematics.py`, `tools/bucket.py`, the `//<pose>` block in the pages) repeat the model's formulas in independent code; the checks catch any divergence (section 6).
- **Generated output** lives in `versions/VNNN-…/`; the root holds only sources, `docs/img/` and the printed kit.

## 2. Stack

| Layer | Technology |
|---|---|
| Model | OpenSCAD (desktop 2026.x, Manifold backend; CGAL only for renders) |
| Calculations, drawings, PDF | Python 3: standard library (system `python3`); numpy, shapely, matplotlib, Pillow (`tools/.venv`) |
| Orchestration | bash scripts (`build_version.sh`, `make.sh`, `check_*.sh`) |
| 3D page with a server | `http.server` (Python) + three.js 0.160 from a CDN, a single HTML file, no build step |
| 3D page without a backend | Vite, three.js, `openscad-wasm-prebuilt` (2025.01 engine) in a web worker, WebXR (AR on Android); tests run in node |
| PDF / screenshots / video | headless Chrome (HTML → PDF, screenshots), puppeteer-core, ffmpeg, poppler |
| CI / hosting | GitHub Actions → GitHub Pages (the WASM page only) |
| Process | git hook `tools/git-hooks/pre-commit`, Claude Code skills and workflows in `.claude/` |

## 3. How the parts connect

```mermaid
flowchart LR
  SCAD["scad/excavator_boom.scad<br/>+ scad/brand/*.scad"]
  subgraph Checks
    OV[check_overlaps.sh]
    MO[check_motion.sh]
  end
  subgraph "Version (build_version.sh)"
    STL[stl/*.stl]
    PNG[renders/*.png]
    REP["docs/*.md<br/>kinematics · strength · bucket"]
    BOM["bom_drawings.py<br/>bom · dxf · parts.pdf"]
    VH[viewer.html]
  end
  subgraph "Printed kit (print3d-parts/make.sh)"
    PS[parts.scad] --> PSTL[stl/**]
    PSTL --> SH["sheets/make_sheets.py<br/>SHEETS.pdf · sheets.json"]
  end
  subgraph Pages
    SRV[viewer.py + viewer/index.html]
    WASM[viewer-wasm/ → dist/]
  end
  SCAD -->|"-D part=overlap/collide → STL"| OV & MO
  SCAD -->|"-D part=… → STL/PNG"| STL & PNG
  SCAD -->|"ECHO BOM_* + SVG part=flat"| BOM
  SCAD -->|"include, part=none"| PS
  SCAD -->|"12 × OFF + ECHO VIEW"| SRV
  SCAD -->|"?raw into the bundle, view_all → OFF"| WASM
  PY["kinematics.py · bucket.py<br/>strength.py · work_range.py"] --> REP
  VJ[views.json] --> SRV & WASM
  VJ --> VP[views.py → PNG]
  SRV --> VH
  WASM -->|"GitHub Actions"| PAGES[GitHub Pages]
  PNG & PSTL & WASM --> MEDIA["tools/media → docs/img/"]
```

## 4. The model's interface

**Input** — `-D` only:

| Parameter | Values |
|---|---|
| `part` | `assembly` (default), a sub-assembly (`boom`, `stick`, `bucket`, `post`, …), a group of plates (`boom_gussets`, …), `flat` / `tubeface` / `flatbrand` / `tubebrand` (2D projections), `overlap` / `collide` (intersection `ov_a`×`ov_b`), `view_all` (every body of the page in one file), `none` (the model as a library) |
| `boom_angle`, `stick_angle`, `bucket_angle` | the pose, degrees; the model itself clamps anything beyond the cylinder stroke |
| `show_*`, `ground_span` | visibility of sub-assemblies and helpers (ground, work envelope, logo) |
| anything else | any Customizer parameter (groups `/* [Name] */` at the top of the file) |

**Output:**

| Channel | Format | Read by |
|---|---|---|
| `ECHO: "=== …"` | text: angle ranges, current pose, bucket | `VERSION.md`, the pages' log |
| `ECHO: "!!! …"` | text: warnings (cylinder cannot reach, dead centre) | the pages, `npm test` (fails on them) |
| `ECHO: VIEW = [[key, value], …]` | list of pairs ≈ JSON (`undef/nan/inf` → `null`) | both pages: joint points, list of bodies, pins |
| `ECHO: BOM_PARAMS / BOM_FLAT / BOM_STRIPS / BOM_WEAR / BOM_SHELL / BOM_TUBES / BOM_ROUND / BOM_PINS` | nested lists | `bom_drawings.py` |
| STL (binary) | sub-assembly geometry | the version, the checks (`stl_volume.py` → cm³), the kit |
| OFF with face colours | mesh + RGB per face | the pages (colour = material / role) |
| SVG | 2D plate outline (`part="flat"`) | `bom_drawings.py` → DXF, dimensions, mass |
| PNG | render (`--render=cgal`, orthographic/perspective) | the version, the sheets, `views.py` |

## 5. Data flows

| From → to | Format | Who / how |
|---|---|---|
| model → checks | intersection STL → volume, cm³ (tolerance 0.05) | `check_overlaps.sh` (plate pairs within a sub-assembly), `check_motion.sh` (moving pairs over the full stroke) |
| model → version | STL, PNG, echo → `VERSION.md` | `build_version.sh` |
| twins → reports | Markdown on stdout, PNG (matplotlib) | `kinematics.py`, `strength.py`, `bucket.py`, `work_range.py` |
| model → BOM and drawings | echo `BOM_*` + SVG → `bom.md`, `bom.csv`, DXF 1:1, `parts.pdf` | `bom_drawings.py` |
| version → README | PNG copies in `docs/img/`; paths in `README*.md` rewritten by `sed` | `build_version.sh` |
| page (server) ↔ `viewer.py` | `GET /api/schema` → parameters as JSON; `GET /api/views` → `views.json`; `POST /api/build {params, fresh}` → `{view, parts{body: {pos, groups[{color, idx}]}}, log, ms}` | 12 OpenSCAD processes in parallel, one OFF per body; cache of recent parameter sets |
| WASM page ↔ worker | `postMessage {id, source, files, defs}` → `{id, view, parts, log, ms}` (buffers transferred) | one run of `part="view_all"`: bodies shifted by `i·spacing` along Y, `offmesh.js` cuts them apart |
| model → WASM page | the `.scad` text is bundled at build time (`?raw`), `views.json` as JSON | Vite; no other inputs (the URL supplies only `?lang`) |
| pose in the browser | angles → `pose()` points → body matrices | JS, no OpenSCAD; the same formulas as the model's `pt_*()` |
| page → saved views | JSON (camera, angles, changed parameters, visibility): clipboard / `views.json` file / `localStorage` | `views.py render` → OpenSCAD PNG |
| model → 1:5 kit | `parts.scad` + `parts.tsv` (TSV, `-` = empty) → one STL per component | `print3d-parts/make.sh`; `check_print.py` → JSON; `make_bom.py` → `BOM.md` |
| kit → sheets | STL (shapely silhouettes) + `assembly.tsv` + `sheets.scad` (PNG) → HTML → PDF | `make_sheets.py` → `SHEETS.pdf`, `sheets.json` (every number), `png/` (from the PDF via poppler) |
| page/PDF → README media | puppeteer screenshots → GIF (ffmpeg); PDF previews | `tools/media/readme_media.sh` → `docs/img/` |
| `main` → Pages | `npm ci` → `npm test` → `vite build` → `dist/` + LICENSE, THIRD-PARTY | `.github/workflows/pages.yml` |

## 6. What must agree and who checks it

| Invariant | Check |
|---|---|
| plates touch but do not overlap | `check_overlaps.sh`; git hook before committing changes in `scad/` |
| moving pairs do not collide | `check_motion.sh` (part of the version build) |
| Python kinematics = the model | angle ranges within 0.1°, bucket linkage branch 0.000 mm: `kinematics.py`, `kinematics.py --check` |
| the model builds in the older WASM engine without warnings | `npm test` (also in CI before publishing) |
| the `//<pose>`, `//<spacemouse>`, `//<viewjson>` blocks are identical in both pages | `npm test` |
| JS pose = the model's echo (bucket tooth) | `npm test` |
| translation complete, legend colours exist in the model's `color(...)` | `npm test` |
| camera conversion page → OpenSCAD | `views.py check` + `media/view_roundtrip.mjs` |
| every kit part is in exactly one step | `make.sh` (`parts.tsv` ↔ `assembly.tsv`) |
| docs: links, anchors, skeleton of bilingual pairs | `check_docs.py` |
| no personal data in a commit (text and PDF, PNG, zip metadata) | `check_personal.py` |

## 7. Where things live

| Folder | Contents |
|---|---|
| `scad/` | the model and the logo polygons |
| `tools/` | twins, generators, checks, `media/`, `git-hooks/`, `dev/` (SpaceMouse helper, agent analytics) |
| `web/` | the pages: `viewer/` with its server `viewer.py`, `viewer-wasm/` (published on Pages) |
| `versions/VNNN-…/` | `stl/`, `renders/`, `docs/`, `bom/`, `dxf/`, `drawings/`, `scad/` (snapshot of the model and scripts), `viewer.html`, `VERSION.md` |
| `print3d-parts/` | the 1:5 kit: `parts.scad`, `parts.tsv`, `assembly.tsv`, `stl/`, `BOM.md`, `sheets/`, `stand/` (a separate display stand with its own `make.sh`) |
| `docs/img/` | README images (updated by `build_version.sh` and `readme_media.sh`) |
| `views.json` | saved views (shared by the pages and `views.py`) |
| `.claude/` | agent skills and workflows |
| `temp/` | drafts and publication media, not in git |
| `_deprecated/` | archive, not used |

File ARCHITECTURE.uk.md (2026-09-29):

[English](ARCHITECTURE.md) · **Українська**

# Програмна архітектура

Коротка карта: з чого складається код, хто кого викликає і в якому форматі йдуть дані. Інженерні подробиці — у [TECHNICAL.uk.md](TECHNICAL.uk.md); геометрія в сторінках, друк проти металу і формат OFF — у [GEOMETRY.uk.md](GEOMETRY.uk.md).

## 1. Принцип

- **Одне джерело правди** — `scad/excavator_boom.scad`. Усе інше — його споживачі.
- **Інтерфейс моделі — командний рядок OpenSCAD**: вхід — `-D назва=значення`, вихід — файл геометрії та рядки `ECHO:` у stderr. Жоден інструмент не має власного списку розмірів: числа читаються з echo, контури — з експорту.
- **Двійники** (`tools/kinematics.py`, `tools/bucket.py`, блок `//<pose>` у сторінках) повторюють формули моделі незалежним кодом; розбіжність ловлять перевірки (розділ 6).
- **Згенероване** живе в `versions/VNNN-…/`; у корені — лише джерела, `docs/img/` і друкований набір.

## 2. Стек

| Шар | Технології |
|---|---|
| Модель | OpenSCAD (настільний 2026.x, рушій Manifold; CGAL — лише для рендерів) |
| Розрахунки, креслення, PDF | Python 3: стандартна бібліотека (системний `python3`); numpy, shapely, matplotlib, Pillow (`tools/.venv`) |
| Оркестрація | bash-скрипти (`build_version.sh`, `make.sh`, `check_*.sh`) |
| 3D-сторінка з сервером | `http.server` (Python) + three.js 0.160 з CDN, один HTML без збирання |
| 3D-сторінка без бекенду | Vite, three.js, `openscad-wasm-prebuilt` (рушій 2025.01) у веб-воркері, WebXR (AR на Android); тест — node |
| PDF / знімки / відео | Chrome headless (HTML → PDF, знімки), puppeteer-core, ffmpeg, poppler |
| CI / хостинг | GitHub Actions → GitHub Pages (лише WASM-сторінка) |
| Процес | git-хук `tools/git-hooks/pre-commit`, skills і workflow Claude Code у `.claude/` |

## 3. Схема зв'язків

```mermaid
flowchart LR
  SCAD["scad/excavator_boom.scad<br/>+ scad/brand/*.scad"]
  subgraph Перевірки
    OV[check_overlaps.sh]
    MO[check_motion.sh]
  end
  subgraph "Версія (build_version.sh)"
    STL[stl/*.stl]
    PNG[renders/*.png]
    REP["docs/*.md<br/>kinematics · strength · bucket"]
    BOM["bom_drawings.py<br/>bom · dxf · parts.pdf"]
    VH[viewer.html]
  end
  subgraph "Друкований набір (print3d-parts/make.sh)"
    PS[parts.scad] --> PSTL[stl/**]
    PSTL --> SH["sheets/make_sheets.py<br/>SHEETS.pdf · sheets.json"]
  end
  subgraph Сторінки
    SRV[viewer.py + viewer/index.html]
    WASM[viewer-wasm/ → dist/]
  end
  SCAD -->|"-D part=overlap/collide → STL"| OV & MO
  SCAD -->|"-D part=… → STL/PNG"| STL & PNG
  SCAD -->|"ECHO BOM_* + SVG part=flat"| BOM
  SCAD -->|"include, part=none"| PS
  SCAD -->|"12 × OFF + ECHO VIEW"| SRV
  SCAD -->|"?raw у збірку, view_all → OFF"| WASM
  PY["kinematics.py · bucket.py<br/>strength.py · work_range.py"] --> REP
  VJ[views.json] --> SRV & WASM
  VJ --> VP[views.py → PNG]
  SRV --> VH
  WASM -->|"GitHub Actions"| PAGES[GitHub Pages]
  PNG & PSTL & WASM --> MEDIA["tools/media → docs/img/"]
```

## 4. Інтерфейс моделі

**Вхід** — лише `-D`:

| Параметр | Значення |
|---|---|
| `part` | `assembly` (типово), вузол (`boom`, `stick`, `bucket`, `post`, …), група пластин (`boom_gussets`, …), `flat` / `tubeface` / `flatbrand` / `tubebrand` (2D-проєкції), `overlap` / `collide` (перетин `ov_a`×`ov_b`), `view_all` (усі тіла сторінки в одному файлі), `none` (модель як бібліотека) |
| `boom_angle`, `stick_angle`, `bucket_angle` | поза, градуси; поза ходом циліндра модель сама обмежує |
| `show_*`, `ground_span` | видимість вузлів і допоміжного (земля, зона досяжності, логотип) |
| решта | будь-який параметр Customizer (групи `/* [Назва] */` на початку файлу) |

**Вихід:**

| Канал | Формат | Хто читає |
|---|---|---|
| `ECHO: "=== …"` | текст: діапазони кутів, поточна поза, ківш | `VERSION.md`, лог сторінок |
| `ECHO: "!!! …"` | текст: попередження (циліндр не дістає, мертва точка) | сторінки, `npm test` (валиться на них) |
| `ECHO: VIEW = [[ключ, значення], …]` | список пар ≈ JSON (`undef/nan/inf` → `null`) | обидві сторінки: точки шарнірів, список тіл, пальці |
| `ECHO: BOM_PARAMS / BOM_FLAT / BOM_STRIPS / BOM_WEAR / BOM_SHELL / BOM_TUBES / BOM_ROUND / BOM_PINS` | вкладені списки | `bom_drawings.py` |
| STL (binary) | геометрія вузлів | версія, перевірки (`stl_volume.py` → см³), набір |
| OFF з кольорами граней | сітка + RGB грані | сторінки (колір = матеріал / роль) |
| SVG | 2D-контур пластини (`part="flat"`) | `bom_drawings.py` → DXF, розміри, маса |
| PNG | рендер (`--render=cgal`, ортогональна/перспектива) | версія, аркуші, `views.py` |

## 5. Потоки даних

| Звідки → куди | Формат | Хто / як |
|---|---|---|
| модель → перевірки | STL перетину → об'єм, см³ (допуск 0.05) | `check_overlaps.sh` (пари пластин вузла), `check_motion.sh` (рухомі пари на всьому ході) |
| модель → версія | STL, PNG, echo → `VERSION.md` | `build_version.sh` |
| двійники → звіти | Markdown у stdout, PNG (matplotlib) | `kinematics.py`, `strength.py`, `bucket.py`, `work_range.py` |
| модель → BOM і креслення | echo `BOM_*` + SVG → `bom.md`, `bom.csv`, DXF 1:1, `parts.pdf` | `bom_drawings.py` |
| версія → README | копії PNG у `docs/img/`; шляхи в `README*.md` переписуються `sed` | `build_version.sh` |
| сторінка (сервер) ↔ `viewer.py` | `GET /api/schema` → JSON параметрів; `GET /api/views` → `views.json`; `POST /api/build {params, fresh}` → `{view, parts{тіло: {pos, groups[{color, idx}]}}, log, ms}` | 12 процесів OpenSCAD паралельно, по OFF на тіло; кеш останніх наборів параметрів |
| WASM-сторінка ↔ воркер | `postMessage {id, source, files, defs}` → `{id, view, parts, log, ms}` (буфери — transfer) | один запуск `part="view_all"`: тіла зсунуті на `i·spacing` по Y, `offmesh.js` розрізає назад |
| модель → WASM-сторінка | текст `.scad` вшивається збіркою (`?raw`), `views.json` — як JSON | Vite; інших входів немає (з адреси — лише `?lang`) |
| поза в браузері | кути → точки `pose()` → матриці тіл | JS, без OpenSCAD; ті самі формули, що `pt_*()` моделі |
| сторінка → ракурси | JSON (камера, кути, змінені параметри, видимість): буфер обміну / файл `views.json` / `localStorage` | `views.py render` → PNG OpenSCAD |
| модель → набір 1:5 | `parts.scad` + `parts.tsv` (TSV, «-» = порожньо) → STL по одному компоненту | `print3d-parts/make.sh`; `check_print.py` → JSON; `make_bom.py` → `BOM.md` |
| набір → аркуші | STL (силуети shapely) + `assembly.tsv` + `sheets.scad` (PNG) → HTML → PDF | `make_sheets.py` → `SHEETS.pdf`, `sheets.json` (усі числа), `png/` (з PDF через poppler) |
| сторінка/PDF → медіа README | знімки puppeteer → GIF (ffmpeg); прев'ю PDF | `tools/media/readme_media.sh` → `docs/img/` |
| `main` → Pages | `npm ci` → `npm test` → `vite build` → `dist/` + LICENSE, THIRD-PARTY | `.github/workflows/pages.yml` |

## 6. Що має збігатися і хто це перевіряє

| Інваріант | Перевірка |
|---|---|
| пластини прилягають, не перекриваються | `check_overlaps.sh`; git-хук перед комітом змін у `scad/` |
| рухомі пари не зіткаються | `check_motion.sh` (у складі збирання версії) |
| Python-кінематика = модель | діапазони кутів до 0.1°, гілка ковша 0.000 мм: `kinematics.py`, `kinematics.py --check` |
| модель будується старішим рушієм WASM без попереджень | `npm test` (також у CI перед публікацією) |
| блоки `//<pose>`, `//<spacemouse>`, `//<viewjson>` однакові в обох сторінках | `npm test` |
| поза JS = echo моделі (зуб ковша) | `npm test` |
| переклад повний, кольори легенди є в `color(...)` моделі | `npm test` |
| перерахунок камери сторінка → OpenSCAD | `views.py check` + `media/view_roundtrip.mjs` |
| кожна деталь набору — рівно в одному кроці | `make.sh` (звірка `parts.tsv` ↔ `assembly.tsv`) |
| документи: посилання, якорі, кістяк двомовних пар | `check_docs.py` |
| у коміті немає особистих даних (текст і метадані PDF, PNG, zip) | `check_personal.py` |

## 7. Де що лежить

| Тека | Вміст |
|---|---|
| `scad/` | модель і полігони логотипа |
| `tools/` | двійники, генератори, перевірки, `media/`, `git-hooks/`, `dev/` (помічник SpaceMouse, аналітика агентів) |
| `web/` | сторінки: `viewer/` із сервером `viewer.py`, `viewer-wasm/` (публікується на Pages) |
| `versions/VNNN-…/` | `stl/`, `renders/`, `docs/`, `bom/`, `dxf/`, `drawings/`, `scad/` (знімок моделі й скриптів), `viewer.html`, `VERSION.md` |
| `print3d-parts/` | набір 1:5: `parts.scad`, `parts.tsv`, `assembly.tsv`, `stl/`, `BOM.md`, `sheets/`, `stand/` (окрема стійка, свій `make.sh`) |
| `docs/img/` | картинки README (оновлюють `build_version.sh` і `readme_media.sh`) |
| `views.json` | збережені ракурси (спільні для сторінок і `views.py`) |
| `.claude/` | skills і workflow агентів |
| `temp/` | чернетки й медіа для публікацій, не в git |
| `_deprecated/` | архів, не використовується |

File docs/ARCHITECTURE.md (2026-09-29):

**English** · [Українська](ARCHITECTURE.uk.md)

# Software architecture

A short map: what the code is made of, who calls whom and in what format the data moves. Engineering detail is in [TECHNICAL.md](TECHNICAL.md); geometry in the pages, print versus steel and the OFF format are in [GEOMETRY.md](GEOMETRY.md).

## 1. Principle

- **One source of truth** — `scad/excavator_boom.scad`. Everything else consumes it.
- **The model's interface is the OpenSCAD command line**: input is `-D name=value`, output is a geometry file plus `ECHO:` lines on stderr. No tool keeps its own list of dimensions: numbers are read from echo, outlines from the export.
- **Twins** (`tools/kinematics.py`, `tools/bucket.py`, the `//<pose>` block in the pages) repeat the model's formulas in independent code; the checks catch any divergence (section 6): `check_twins.py` for Python, `npm test` for the pages.
- **Generated output** lives in `latest/` (the current version, the 1:5 kit inside it) and `versions/VNNN-…/` (the archive); the root holds only sources and `docs/img/`. Intermediate files go to `build/`, which is not in git.

## 2. Stack

| Layer | Technology |
|---|---|
| Model | OpenSCAD (desktop 2026.x, Manifold backend; CGAL only for renders) |
| Calculations, drawings, PDF | Python 3: standard library (system `python3`); numpy, shapely, matplotlib, Pillow (`tools/.venv`) |
| Orchestration | bash scripts (`build_version.sh`, `make.sh`, `check_*.sh`) |
| 3D page with a server | `http.server` (Python) + three.js 0.160 from a CDN, a single HTML file, no build step |
| 3D page without a backend | Vite, three.js, `openscad-wasm-prebuilt` (2025.01 engine) in a web worker, WebXR (AR on Android); tests run in node |
| PDF / screenshots / video | headless Chrome (HTML → PDF, screenshots), puppeteer-core, ffmpeg, poppler |
| CI / hosting | GitHub Actions → GitHub Pages (the WASM page only) |
| Process | git hook `tools/git-hooks/pre-commit`, linters `tools/lint.sh` (ruff, shellcheck), Claude Code skills and workflows in `.claude/` |

## 3. How the parts connect

```mermaid
flowchart LR
  SCAD["scad/excavator_boom.scad<br/>+ scad/brand/*.scad"]
  subgraph Checks
    OV[check_overlaps.sh]
    MO[check_motion.sh]
    TW[check_twins.py]
  end
  subgraph "Version → latest/ (build_version.sh)"
    STL[stl/*.stl]
    PNG[renders/*.png]
    REP["docs/*.md<br/>kinematics · strength · bucket"]
    BOM["bom_drawings.py<br/>bom · dxf · parts.pdf"]
    VH[viewer.html]
  end
  subgraph "Printed kit → latest/print3d/ (print3d-parts/make.sh)"
    PS[parts.scad] --> PSTL[stl/**]
    PSTL --> SH["sheets/make_sheets.py<br/>SHEETS.pdf · sheets.json"]
    PSTL --> DR["model_drive.py<br/>DRIVE.md"]
  end
  subgraph Pages
    SRV[viewer.py + viewer/index.html]
    WASM[viewer-wasm/ → dist/]
  end
  SCAD -->|"-D part=overlap/collide → STL"| OV & MO
  SCAD -->|"-D part=… → STL/PNG"| STL & PNG
  SCAD -->|"ECHO BOM_* + SVG part=flat"| BOM
  SCAD -->|"include, part=none"| PS
  SCAD -->|"12 × OFF + ECHO VIEW"| SRV
  SCAD -->|"?raw into the bundle, view_all → OFF"| WASM
  PY["kinematics.py · bucket.py<br/>strength.py · work_range.py"] --> REP
  SCAD -->|"-D TWIN__=echo(…)"| TW
  PY --> TW
  VJ[views.json] --> SRV & WASM
  VJ --> VP[views.py → PNG]
  SRV --> VH
  WASM -->|"GitHub Actions"| PAGES[GitHub Pages]
  PNG & PSTL & WASM --> MEDIA["tools/media → docs/img/"]
```

## 4. The model's interface

**Input** — `-D` only:

| Parameter | Values |
|---|---|
| `part` | `assembly` (default), a sub-assembly (`boom`, `stick`, `bucket`, `post`, …), a group of plates (`boom_gussets`, …), `flat` / `tubeface` / `flatbrand` / `tubebrand` (2D projections), `overlap` / `collide` (intersection `ov_a`×`ov_b`), `view_all` (every body of the page in one file), `none` (the model as a library) |
| `boom_angle`, `stick_angle`, `bucket_angle` | the pose, degrees; the model itself clamps anything beyond the cylinder stroke |
| `show_*`, `ground_span` | visibility of sub-assemblies and helpers (ground, work envelope, logo) |
| anything else | any Customizer parameter (groups `/* [Name] */` at the top of the file) |

**Output:**

| Channel | Format | Read by |
|---|---|---|
| `ECHO: "=== …"` | text: angle ranges, current pose, bucket | `VERSION.md`, the pages' log |
| `ECHO: "!!! …"` | text: warnings (cylinder cannot reach, dead centre) | the pages, `npm test` (fails on them) |
| `ECHO: VIEW = [[key, value], …]` | list of pairs ≈ JSON (`undef/nan/inf` → `null`) | both pages: joint points, list of bodies, pins |
| `ECHO: BOM_PARAMS / BOM_FLAT / BOM_STRIPS / BOM_WEAR / BOM_SHELL / BOM_TUBES / BOM_ROUND / BOM_PINS` | nested lists | `bom_drawings.py` |
| STL (binary) | sub-assembly geometry | the version, the checks (`stl_volume.py` → cm³), the kit |
| OFF with face colours | mesh + RGB per face | the pages (colour = material / role) |
| SVG | 2D plate outline (`part="flat"`) | `bom_drawings.py` → DXF, dimensions, mass |
| PNG | render (`--render=cgal`, orthographic/perspective) | the version, the sheets, `views.py` |

## 5. Data flows

| From → to | Format | Who / how |
|---|---|---|
| model → checks | intersection STL → volume, cm³ (tolerance 0.05) | `check_overlaps.sh` (plate pairs within a sub-assembly), `check_motion.sh` (moving pairs over the full stroke) |
| model ↔ Python twins | the twins' parameters and results as OpenSCAD expressions in one `-D TWIN__=echo(…)` → a list ≈ JSON; tolerance 0.05 mm / 0.01° | `check_twins.py` (in `build_version.sh` and the git hook) |
| model → version | STL, PNG, echo → `VERSION.md`, all in `build/version/` | `build_version.sh` |
| new build ↔ `latest/` | STL as triangle sets, reports and angle ranges as text without numbers and dates → exit code 0 (same) / 1 (changed) | `compare_build.py`: changed — the old `latest/` goes to `versions/` (git mv), a new version; same — `latest/` refreshed in place |
| twins → reports | Markdown on stdout, PNG (matplotlib) | `kinematics.py`, `strength.py`, `bucket.py`, `work_range.py` |
| model → BOM and drawings | echo `BOM_*` + SVG → `bom.md`, `bom.csv`, DXF 1:1, `parts.pdf` | `bom_drawings.py` |
| version → README | PNG copies in `docs/img/`; `README*.md` link to `latest/…` (stable paths). A drawing page is copied only if it changed outside the dated header and footer | `build_version.sh`, `copy_if_changed.py` |
| page (server) ↔ `viewer.py` | `GET /api/schema` → parameters as JSON; `GET /api/views` → `views.json`; `POST /api/build {params, fresh}` → `{view, parts{body: {pos, groups[{color, idx}]}}, log, ms}` | 12 OpenSCAD processes in parallel, one OFF per body; cache of recent parameter sets |
| WASM page ↔ worker | `postMessage {id, source, files, defs}` → `{id, view, parts, log, ms}` (buffers transferred) | one run of `part="view_all"`: bodies shifted by `i·spacing` along Y, `offmesh.js` cuts them apart |
| model → WASM page | the `.scad` text is bundled at build time (`?raw`), `views.json` as JSON | Vite; no other inputs (the URL supplies only `?lang`) |
| pose in the browser | angles → `pose()` points → body matrices | JS, no OpenSCAD; the same formulas as the model's `pt_*()` |
| page → saved views | JSON (camera, angles, changed parameters, visibility): clipboard / `views.json` file / `localStorage` | `views.py render` → OpenSCAD PNG |
| model → 1:5 kit | `parts.scad` + `parts.tsv` (TSV, `-` = empty) → one STL per component, in `build/print3d/` → `latest/print3d/` as sub-version VNNN.K (the previous one → `print3d-history/`) | `print3d-parts/make.sh` (only if the model matches `latest/scad/`); `check_print.py` → JSON; `make_bom.py` → `BOM.md`; `model_drive.py` → `DRIVE.md` |
| kit → sheets | STL (shapely silhouettes) + `assembly.tsv` + `sheets.scad` (PNG) → HTML → PDF | `make_sheets.py` → `SHEETS.pdf`, `sheets.json` (every number); `png/` previews (from the PDF via poppler) stay in `build/`, the bucket sheet goes to `docs/img/` through `copy_if_changed.py` |
| page/PDF → README media | puppeteer screenshots → GIF (ffmpeg); PDF previews | `tools/media/readme_media.sh` → `docs/img/` |
| `main` → Pages | `npm ci` → `npm test` → `vite build` → `dist/` + LICENSE, THIRD-PARTY | `.github/workflows/pages.yml` |

## 6. What must agree and who checks it

| Invariant | Check |
|---|---|
| plates touch but do not overlap | `check_overlaps.sh`; git hook before committing changes in `scad/` |
| Python and shell code free of real errors | `tools/lint.sh` (ruff: pyflakes and bugbear; shellcheck) — run by hand |
| moving pairs do not collide | `check_motion.sh` (part of the version build) |
| Python twins = the model (`kinematics.py`, `bucket.py`) | `check_twins.py`: every parameter, the joint points and cylinder lengths in 27 poses, the angle ranges, the bucket profile — in one OpenSCAD run (≈ 0.3 s); stops the version build, runs in the git hook when `scad/` or a twin is committed |
| the model builds in the older WASM engine without warnings | `npm test` (also in CI before publishing) |
| the `//<pose>`, `//<spacemouse>`, `//<viewjson>` blocks are identical in both pages | `npm test` |
| JS pose = the model's echo (bucket tooth) | `npm test` |
| translation complete, legend colours exist in the model's `color(...)` | `npm test` |
| camera conversion page → OpenSCAD | `views.py check` + `media/view_roundtrip.mjs` |
| every kit part is in exactly one step | `make.sh` (`parts.tsv` ↔ `assembly.tsv`) |
| the kit is built from the model of `latest/` | `make.sh` refuses if `scad/` differs from `latest/scad/` |
| a new version number only when something real changed | `compare_build.py` inside `build_version.sh` (`--new` to force) |
| docs: links, anchors, skeleton of bilingual pairs | `check_docs.py` |
| no personal data in a commit (text and PDF, PNG, zip metadata) | `check_personal.py` |

## 7. Where things live

| Folder | Contents |
|---|---|
| `scad/` | the model and the logo polygons |
| `tools/` | twins, generators, checks, `media/`, `git-hooks/`, `dev/` (SpaceMouse helper, agent analytics) |
| `web/` | the pages: `viewer/` with its server `viewer.py`, `viewer-wasm/` (published on Pages); how to use them — [web/README.md](../web/README.md) |
| `latest/` | the current version: `stl/`, `renders/`, `docs/`, `bom/`, `dxf/`, `drawings/`, `scad/` (snapshot of the model and scripts), `viewer.html`, `VERSION.md`; `print3d/` — the current 1:5 kit (VNNN.K), `print3d-history/` — its earlier sub-versions |
| `versions/VNNN-…/` | the archive: a former `latest/` moves here (git mv) when the geometry or the report numbers change |
| `build/` | intermediate files and check logs, drawing and sheet PNG previews; not in git |
| `print3d-parts/` | sources of the 1:5 kit: `parts.scad`, `parts.tsv`, `assembly.tsv`, `make.sh`, `group.sh`, `sheets/` (generator), `stand/` (a separate display stand with its own `make.sh` and STL); the output goes to `latest/print3d/`; description — [print3d-parts/README.md](../print3d-parts/README.md) (Ukrainian) |
| `docs/` | the documents: TECHNICAL, QUICKSTART, ARCHITECTURE, GEOMETRY, STORY (`.md` / `.uk.md`); README and SAFETY stay in the root |
| `docs/img/` | README images (updated by `build_version.sh` and `readme_media.sh`) |
| `views.json` | saved views (shared by the pages and `views.py`) |
| `.claude/` | agent skills and workflows |
| `temp/` | drafts and publication media, not in git |
| `_deprecated/` | archive, not used |

Key files by role (the pages and the printed kit are described in their own READMEs):

| File | What it does |
|---|---|
| `scad/excavator_boom.scad` | **The model.** All parameters at the top of the file (Customizer groups); the angles are the primary parameters, their ranges are derived from the cylinder lengths and printed by `echo()` |
| `tools/kinematics.py` | Kinematics twin: angle ranges, moment arms, tooth force, work envelope; `--search` fits the mounting positions |
| `tools/bucket.py` | Bucket twin: capacity (struck / heaped), mass, carry and dump angles, 2D clearances of the moving pairs over the full stroke, strength of the ears, pins E/Q and welds. Run with `tools/.venv/bin/python` |
| `tools/strength.py` | Member statics plus strength of materials: N/V/M diagrams, tubes and doublers, pins, bushings, welds; section comparison (`--boom 120x80x5 --stick 100x60x5`) |
| `tools/work_range.py` | Working-range drawing with dimensions A…J, swept over the full stroke of all three cylinders; `--lang uk\|en` |
| `tools/check_twins.py` | The Python twins against the model (section 6) |
| `tools/check_overlaps.sh`, `tools/check_motion.sh` | Plates abut but never overlap; moving pairs do not collide over the full cylinder stroke |
| `tools/build_version.sh`, `tools/compare_build.py` | The version build (checks → STL → renders → reports → BOM and drawings → `latest/`) and the "new version or refresh in place" decision |
| `tools/bom_drawings.sh` → `bom_drawings.py` | BOM, 1:1 DXF of every plate, PDF sketches — from the model's echo and plate projections, with no separate list of dimensions |
| `views.json` → `tools/views.py` | Views saved on the 3D page become reproducible renders: `list` / `flags` / `render NAME` / `check` |
| `scad/brand/` → `tools/brand_merge.py` | The logo: one polygon per size (the generator's ~800 zero-area slivers made every WASM rebuild ≈ 3× slower); where it goes is the `brand_marks` table in the model |
| `tools/page_style.py`, `tools/author.py` | One look for every PDF (header, footer); authorship from `AUTHORS` |
| `tools/copy_if_changed.py` | Copies a PDF page PNG into `docs/img/` only if the page changed outside its dated header and footer — otherwise every build would commit a new binary |
| `tools/media/` | README media (`readme_media.sh`: the page tour GIF, PDF previews) and publication media (`make_media.sh` → `temp/media/`) |
| `tools/check_personal.py` | Before every commit: personal data in the staged text and in binary metadata (PDF, PNG, zip-based `.3mf`); the machine-specific patterns are read at run time, none is stored in the script |
| `tools/check_docs.py` | After editing the docs: links, anchors, the skeleton of the bilingual pairs |
| `tools/lint.sh` | ruff (`ruff.toml`) and shellcheck (`.shellcheckrc`); Python dependencies in `tools/requirements.txt`, the linters in `tools/requirements-dev.txt` |
| `tools/git-hooks/pre-commit` | Before committing `scad/` or a twin: `check_twins.py` and the overlap check. Enable once: `git config core.hooksPath tools/git-hooks` |
| `CLAUDE.md`, `.claude/skills/`, `.claude/workflows/` | Rules for Claude Code; the project skills; multi-agent workflows (`design-review`, `research-sweep`) whose agents write their results straight into files |

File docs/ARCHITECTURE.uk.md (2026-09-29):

[English](ARCHITECTURE.md) · **Українська**

# Програмна архітектура

Коротка карта: з чого складається код, хто кого викликає і в якому форматі йдуть дані. Інженерні подробиці — у [TECHNICAL.uk.md](TECHNICAL.uk.md); геометрія в сторінках, друк проти металу і формат OFF — у [GEOMETRY.uk.md](GEOMETRY.uk.md).

## 1. Принцип

- **Одне джерело правди** — `scad/excavator_boom.scad`. Усе інше — його споживачі.
- **Інтерфейс моделі — командний рядок OpenSCAD**: вхід — `-D назва=значення`, вихід — файл геометрії та рядки `ECHO:` у stderr. Жоден інструмент не має власного списку розмірів: числа читаються з echo, контури — з експорту.
- **Двійники** (`tools/kinematics.py`, `tools/bucket.py`, блок `//<pose>` у сторінках) повторюють формули моделі незалежним кодом; розбіжність ловлять перевірки (розділ 6): `check_twins.py` для Python, `npm test` для сторінок.
- **Згенероване** живе в `latest/` (поточна версія, набір 1:5 — у ній) і `versions/VNNN-…/` (архів); у корені — лише джерела й `docs/img/`. Проміжне — у `build/`, його немає в git.

## 2. Стек

| Шар | Технології |
|---|---|
| Модель | OpenSCAD (настільний 2026.x, рушій Manifold; CGAL — лише для рендерів) |
| Розрахунки, креслення, PDF | Python 3: стандартна бібліотека (системний `python3`); numpy, shapely, matplotlib, Pillow (`tools/.venv`) |
| Оркестрація | bash-скрипти (`build_version.sh`, `make.sh`, `check_*.sh`) |
| 3D-сторінка з сервером | `http.server` (Python) + three.js 0.160 з CDN, один HTML без збирання |
| 3D-сторінка без бекенду | Vite, three.js, `openscad-wasm-prebuilt` (рушій 2025.01) у веб-воркері, WebXR (AR на Android); тест — node |
| PDF / знімки / відео | Chrome headless (HTML → PDF, знімки), puppeteer-core, ffmpeg, poppler |
| CI / хостинг | GitHub Actions → GitHub Pages (лише WASM-сторінка) |
| Процес | git-хук `tools/git-hooks/pre-commit`, лінтери `tools/lint.sh` (ruff, shellcheck), skills і workflow Claude Code у `.claude/` |

## 3. Схема зв'язків

```mermaid
flowchart LR
  SCAD["scad/excavator_boom.scad<br/>+ scad/brand/*.scad"]
  subgraph Перевірки
    OV[check_overlaps.sh]
    MO[check_motion.sh]
    TW[check_twins.py]
  end
  subgraph "Версія → latest/ (build_version.sh)"
    STL[stl/*.stl]
    PNG[renders/*.png]
    REP["docs/*.md<br/>kinematics · strength · bucket"]
    BOM["bom_drawings.py<br/>bom · dxf · parts.pdf"]
    VH[viewer.html]
  end
  subgraph "Друкований набір → latest/print3d/ (print3d-parts/make.sh)"
    PS[parts.scad] --> PSTL[stl/**]
    PSTL --> SH["sheets/make_sheets.py<br/>SHEETS.pdf · sheets.json"]
    PSTL --> DR["model_drive.py<br/>DRIVE.md"]
  end
  subgraph Сторінки
    SRV[viewer.py + viewer/index.html]
    WASM[viewer-wasm/ → dist/]
  end
  SCAD -->|"-D part=overlap/collide → STL"| OV & MO
  SCAD -->|"-D part=… → STL/PNG"| STL & PNG
  SCAD -->|"ECHO BOM_* + SVG part=flat"| BOM
  SCAD -->|"include, part=none"| PS
  SCAD -->|"12 × OFF + ECHO VIEW"| SRV
  SCAD -->|"?raw у збірку, view_all → OFF"| WASM
  PY["kinematics.py · bucket.py<br/>strength.py · work_range.py"] --> REP
  SCAD -->|"-D TWIN__=echo(…)"| TW
  PY --> TW
  VJ[views.json] --> SRV & WASM
  VJ --> VP[views.py → PNG]
  SRV --> VH
  WASM -->|"GitHub Actions"| PAGES[GitHub Pages]
  PNG & PSTL & WASM --> MEDIA["tools/media → docs/img/"]
```

## 4. Інтерфейс моделі

**Вхід** — лише `-D`:

| Параметр | Значення |
|---|---|
| `part` | `assembly` (типово), вузол (`boom`, `stick`, `bucket`, `post`, …), група пластин (`boom_gussets`, …), `flat` / `tubeface` / `flatbrand` / `tubebrand` (2D-проєкції), `overlap` / `collide` (перетин `ov_a`×`ov_b`), `view_all` (усі тіла сторінки в одному файлі), `none` (модель як бібліотека) |
| `boom_angle`, `stick_angle`, `bucket_angle` | поза, градуси; поза ходом циліндра модель сама обмежує |
| `show_*`, `ground_span` | видимість вузлів і допоміжного (земля, зона досяжності, логотип) |
| решта | будь-який параметр Customizer (групи `/* [Назва] */` на початку файлу) |

**Вихід:**

| Канал | Формат | Хто читає |
|---|---|---|
| `ECHO: "=== …"` | текст: діапазони кутів, поточна поза, ківш | `VERSION.md`, лог сторінок |
| `ECHO: "!!! …"` | текст: попередження (циліндр не дістає, мертва точка) | сторінки, `npm test` (валиться на них) |
| `ECHO: VIEW = [[ключ, значення], …]` | список пар ≈ JSON (`undef/nan/inf` → `null`) | обидві сторінки: точки шарнірів, список тіл, пальці |
| `ECHO: BOM_PARAMS / BOM_FLAT / BOM_STRIPS / BOM_WEAR / BOM_SHELL / BOM_TUBES / BOM_ROUND / BOM_PINS` | вкладені списки | `bom_drawings.py` |
| STL (binary) | геометрія вузлів | версія, перевірки (`stl_volume.py` → см³), набір |
| OFF з кольорами граней | сітка + RGB грані | сторінки (колір = матеріал / роль) |
| SVG | 2D-контур пластини (`part="flat"`) | `bom_drawings.py` → DXF, розміри, маса |
| PNG | рендер (`--render=cgal`, ортогональна/перспектива) | версія, аркуші, `views.py` |

## 5. Потоки даних

| Звідки → куди | Формат | Хто / як |
|---|---|---|
| модель → перевірки | STL перетину → об'єм, см³ (допуск 0.05) | `check_overlaps.sh` (пари пластин вузла), `check_motion.sh` (рухомі пари на всьому ході) |
| модель ↔ Python-двійники | параметри й результати двійників як вирази OpenSCAD в одному `-D TWIN__=echo(…)` → список ≈ JSON; допуск 0.05 мм / 0.01° | `check_twins.py` (у `build_version.sh` і git-хуку) |
| модель → версія | STL, PNG, echo → `VERSION.md`, усе в `build/version/` | `build_version.sh` |
| нове збирання ↔ `latest/` | STL — набором трикутників, звіти й діапазони кутів — текстом без номерів і дат → код виходу 0 (те саме) / 1 (змінилось) | `compare_build.py`: змінилось — старий `latest/` у `versions/` (git mv), нова версія; те саме — `latest/` оновлюється на місці |
| двійники → звіти | Markdown у stdout, PNG (matplotlib) | `kinematics.py`, `strength.py`, `bucket.py`, `work_range.py` |
| модель → BOM і креслення | echo `BOM_*` + SVG → `bom.md`, `bom.csv`, DXF 1:1, `parts.pdf` | `bom_drawings.py` |
| версія → README | копії PNG у `docs/img/`; `README*.md` посилаються на `latest/…` (шляхи сталі). Сторінка креслення копіюється, лише якщо змінилась поза шапкою й підвалом із датою | `build_version.sh`, `copy_if_changed.py` |
| сторінка (сервер) ↔ `viewer.py` | `GET /api/schema` → JSON параметрів; `GET /api/views` → `views.json`; `POST /api/build {params, fresh}` → `{view, parts{тіло: {pos, groups[{color, idx}]}}, log, ms}` | 12 процесів OpenSCAD паралельно, по OFF на тіло; кеш останніх наборів параметрів |
| WASM-сторінка ↔ воркер | `postMessage {id, source, files, defs}` → `{id, view, parts, log, ms}` (буфери — transfer) | один запуск `part="view_all"`: тіла зсунуті на `i·spacing` по Y, `offmesh.js` розрізає назад |
| модель → WASM-сторінка | текст `.scad` вшивається збіркою (`?raw`), `views.json` — як JSON | Vite; інших входів немає (з адреси — лише `?lang`) |
| поза в браузері | кути → точки `pose()` → матриці тіл | JS, без OpenSCAD; ті самі формули, що `pt_*()` моделі |
| сторінка → ракурси | JSON (камера, кути, змінені параметри, видимість): буфер обміну / файл `views.json` / `localStorage` | `views.py render` → PNG OpenSCAD |
| модель → набір 1:5 | `parts.scad` + `parts.tsv` (TSV, «-» = порожньо) → STL по одному компоненту, у `build/print3d/` → `latest/print3d/` підверсією VNNN.K (попередня → `print3d-history/`) | `print3d-parts/make.sh` (лише якщо модель збігається з `latest/scad/`); `check_print.py` → JSON; `make_bom.py` → `BOM.md`; `model_drive.py` → `DRIVE.md` |
| набір → аркуші | STL (силуети shapely) + `assembly.tsv` + `sheets.scad` (PNG) → HTML → PDF | `make_sheets.py` → `SHEETS.pdf`, `sheets.json` (усі числа); прев'ю `png/` (з PDF через poppler) лишаються в `build/`, аркуш ковша йде в `docs/img/` через `copy_if_changed.py` |
| сторінка/PDF → медіа README | знімки puppeteer → GIF (ffmpeg); прев'ю PDF | `tools/media/readme_media.sh` → `docs/img/` |
| `main` → Pages | `npm ci` → `npm test` → `vite build` → `dist/` + LICENSE, THIRD-PARTY | `.github/workflows/pages.yml` |

## 6. Що має збігатися і хто це перевіряє

| Інваріант | Перевірка |
|---|---|
| пластини прилягають, не перекриваються | `check_overlaps.sh`; git-хук перед комітом змін у `scad/` |
| у коді Python і shell немає справжніх помилок | `tools/lint.sh` (ruff: pyflakes і bugbear; shellcheck) — запускається вручну |
| рухомі пари не зіткаються | `check_motion.sh` (у складі збирання версії) |
| Python-двійники = модель (`kinematics.py`, `bucket.py`) | `check_twins.py`: кожен параметр, точки шарнірів і довжини циліндрів у 27 позах, діапазони кутів, профіль ковша — одним запуском OpenSCAD (≈ 0.3 с); зупиняє збирання версії, працює в git-хуку при коміті `scad/` чи двійника |
| модель будується старішим рушієм WASM без попереджень | `npm test` (також у CI перед публікацією) |
| блоки `//<pose>`, `//<spacemouse>`, `//<viewjson>` однакові в обох сторінках | `npm test` |
| поза JS = echo моделі (зуб ковша) | `npm test` |
| переклад повний, кольори легенди є в `color(...)` моделі | `npm test` |
| перерахунок камери сторінка → OpenSCAD | `views.py check` + `media/view_roundtrip.mjs` |
| кожна деталь набору — рівно в одному кроці | `make.sh` (звірка `parts.tsv` ↔ `assembly.tsv`) |
| набір зібраний з моделі `latest/` | `make.sh` відмовляє, якщо `scad/` відрізняється від `latest/scad/` |
| новий номер версії — лише коли змінилось по суті | `compare_build.py` у `build_version.sh` (`--new` — примусово) |
| документи: посилання, якорі, кістяк двомовних пар | `check_docs.py` |
| у коміті немає особистих даних (текст і метадані PDF, PNG, zip) | `check_personal.py` |

## 7. Де що лежить

| Тека | Вміст |
|---|---|
| `scad/` | модель і полігони логотипа |
| `tools/` | двійники, генератори, перевірки, `media/`, `git-hooks/`, `dev/` (помічник SpaceMouse, аналітика агентів) |
| `web/` | сторінки: `viewer/` із сервером `viewer.py`, `viewer-wasm/` (публікується на Pages); як ними користуватися — [web/README.uk.md](../web/README.uk.md) |
| `latest/` | поточна версія: `stl/`, `renders/`, `docs/`, `bom/`, `dxf/`, `drawings/`, `scad/` (знімок моделі й скриптів), `viewer.html`, `VERSION.md`; `print3d/` — поточний набір 1:5 (VNNN.K), `print3d-history/` — його попередні підверсії |
| `versions/VNNN-…/` | архів: сюди переїжджає колишній `latest/` (git mv), коли змінились геометрія чи числа звітів |
| `build/` | проміжне й журнали перевірок, PNG-прев'ю ескізів і аркушів; не в git |
| `print3d-parts/` | джерела набору 1:5: `parts.scad`, `parts.tsv`, `assembly.tsv`, `make.sh`, `group.sh`, `sheets/` (генератор), `stand/` (окрема стійка зі своїм `make.sh` і STL); результат — у `latest/print3d/`; опис — [print3d-parts/README.md](../print3d-parts/README.md) |
| `docs/` | документи: TECHNICAL, QUICKSTART, ARCHITECTURE, GEOMETRY, STORY (`.md` / `.uk.md`); README і SAFETY — у корені |
| `docs/img/` | картинки README (оновлюють `build_version.sh` і `readme_media.sh`) |
| `views.json` | збережені ракурси (спільні для сторінок і `views.py`) |
| `.claude/` | skills і workflow агентів |
| `temp/` | чернетки й медіа для публікацій, не в git |
| `_deprecated/` | архів, не використовується |

Ключові файли за роллю (сторінки й друкований набір описані у своїх README):

| Файл | Що робить |
|---|---|
| `scad/excavator_boom.scad` | **Модель.** Усі параметри — на початку файлу (групи Customizer); кути — первинні параметри, їхні діапазони обчислюються з довжин циліндрів і виводяться через `echo()` |
| `tools/kinematics.py` | Двійник кінематики: діапазони кутів, плечі моментів, зусилля на зубі, робоча зона; `--search` — підбір положень кріплень |
| `tools/bucket.py` | Двійник ковша: місткість (врівень / з «шапкою»), маса, кути утримання й висипання, 2D-зазори рухомих пар на всьому ході, міцність вух, пальців E/Q і швів. Запуск — `tools/.venv/bin/python` |
| `tools/strength.py` | Статика ланок + опір матеріалів: епюри N/V/M, труби й накладки, пальці, втулки, шви; порівняння профілів (`--boom 120x80x5 --stick 100x60x5`) |
| `tools/work_range.py` | Креслення робочої зони з розмірами A…J перебором усього ходу трьох циліндрів; `--lang uk\|en` |
| `tools/check_twins.py` | Звірка Python-двійників з моделлю (розділ 6) |
| `tools/check_overlaps.sh`, `tools/check_motion.sh` | Пластини прилягають, але не перекриваються; рухомі пари не зіткаються на всьому ході циліндрів |
| `tools/build_version.sh`, `tools/compare_build.py` | Збирання версії (перевірки → STL → рендери → звіти → BOM і креслення → `latest/`) і рішення «нова версія чи оновлення на місці» |
| `tools/bom_drawings.sh` → `bom_drawings.py` | BOM, DXF 1:1 кожної пластини, PDF-ескізи — з echo моделі та проєкцій пластин, без окремого списку розмірів |
| `views.json` → `tools/views.py` | Ракурси, збережені в 3D-сторінці, стають відтворюваними рендерами: `list` / `flags` / `render НАЗВА` / `check` |
| `scad/brand/` → `tools/brand_merge.py` | Логотип: один polygon() на розмір (~800 скалок нульової площі з генератора втричі сповільнювали кожну перебудову у WASM); де він стоїть — таблиця `brand_marks` у моделі |
| `tools/page_style.py`, `tools/author.py` | Один вигляд усіх PDF (шапка, підвал); авторство з `AUTHORS` |
| `tools/copy_if_changed.py` | Копіює PNG сторінки PDF у `docs/img/`, лише якщо сторінка змінилась поза шапкою й підвалом із датою — інакше кожне збирання комітило б новий двійковий файл |
| `tools/media/` | Медіа README (`readme_media.sh`: GIF-тур сторінкою, прев'ю PDF) і медіа для публікацій (`make_media.sh` → `temp/media/`) |
| `tools/check_personal.py` | Перед кожним комітом: особисті дані в staged-тексті й метаданих двійкових файлів (PDF, PNG, zip-формати на кшталт `.3mf`); особисте цієї машини скрипт бере під час запуску, у ньому самому цього немає |
| `tools/check_docs.py` | Після правок документації: посилання, якорі, кістяк двомовних пар |
| `tools/lint.sh` | ruff (`ruff.toml`) і shellcheck (`.shellcheckrc`); залежності Python — `tools/requirements.txt`, лінтери — `tools/requirements-dev.txt` |
| `tools/git-hooks/pre-commit` | Перед комітом `scad/` чи двійника: `check_twins.py` і перевірка перекриттів. Увімкнути один раз: `git config core.hooksPath tools/git-hooks` |
| `CLAUDE.md`, `.claude/skills/`, `.claude/workflows/` | Правила для Claude Code; skills проєкту; багатоагентні workflow (`design-review`, `research-sweep`), агенти яких одразу пишуть результат у файли |

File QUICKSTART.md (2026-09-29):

**English** · [Українська](QUICKSTART.uk.md)

# Quick start

> ⚠️ **Ihor Ivaniuk (@IBITLAB) is the originator and product owner: organises the AI's work, sets the tasks, makes the decisions. The execution — geometry, calculations, drawings, code and texts — is done by AI (Claude Code by Anthropic).** No qualified engineer has checked the model, the calculations or the drawings, and no machine has ever been built or tested from them. A mini excavator maims and kills. No warranty of any kind; the author accepts no liability for harm to life, health or property. Everything is at your own risk and on your own responsibility. The full disclaimer is in [README.md, section Disclaimer](README.md#disclaimer).

A parametric model of the working equipment of a towable mini excavator — boom, stick, linkage and a **300 mm bucket** — built around already-purchased hydraulic cylinders. One OpenSCAD model produces STL files, drawings (DXF, PDF), a bill of materials, the calculations and an interactive 3D page. The overview and the live 3D model are in [README.md](README.md), the details in [TECHNICAL.md](TECHNICAL.md).

## What you need

| For what | Dependency |
|---|---|
| The model, building versions, the 3D page with a server | **OpenSCAD** — a nightly build with the Manifold engine (verified on 2025.07 and 2026.09; the stable 2021.01 will not do), `openscad` on the PATH; **Python 3** |
| PDF sketches, the bucket report | nothing to install: `tools/.venv` (matplotlib, shapely) is created on the first build |
| The 3D page without a backend (WASM) | **Node.js ≥ 20.19** |
| The printed kit and its 1:1 sorting sheets (`print3d-parts/make.sh`) | **Chrome** (HTML → PDF) and **poppler** (`brew install poppler`: `pdftoppm`, `pdfinfo`, `pdftotext` — previews and page checks from the PDF itself; without it the previews are screenshots of the HTML) |
| README media: the page tour GIF and the PDF previews (`tools/media/readme_media.sh`) | **ffmpeg**, **poppler**, Chrome and `puppeteer-core` for Node (once: `npm i --no-save --prefix tools/media puppeteer-core`; it also puts page numbers on the PDFs) |
| A SpaceMouse 3D mouse (optional) | Chrome / Edge; on macOS the 3Dconnexion driver is switched off for the session — the `:sm` commands do that for you |

## Core commands

```bash
# open the model: boom / stick / bucket angles are the first parameters in the Customizer
openscad scad/excavator_boom.scad

# build a version → versions/VNNN-date-time/ (STL, renders, reports, BOM, DXF, PDF, viewer.html); --commit also commits it
tools/build_version.sh --commit "what changed"

# checks only: plates abut without overlapping / moving pairs never collide over the full cylinder stroke
tools/check_overlaps.sh
tools/check_motion.sh

# the 1:5 printed kit: STL of every component, checks, BOM, 1:1 sorting sheets (SHEETS.pdf)
print3d-parts/make.sh

# the 3D page in a browser: angles are instant, other parameters rebuild through OpenSCAD in ≈ 0.4 s
web/viewer.sh

# the same without a backend: OpenSCAD-WASM in the browser (the first run does npm install itself)
web/viewer-wasm.sh              # dev server;  build → a static site in dist/;  preview;  test

# with a SpaceMouse on macOS: the driver is released while the server runs and restored on exit
tools/dev/with-spacemouse.sh web/viewer.sh
cd web/viewer-wasm && npm run preview:sm
```

Once after cloning: `git config core.hooksPath tools/git-hooks` — this checks plate overlaps before every commit that touches the model.

The results of the last build are in the `versions/` folder with the highest number: `drawings/parts.pdf`, `dxf/`, `bom/bom.md`, `docs/`, `viewer.html`.

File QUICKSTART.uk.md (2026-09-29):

[English](QUICKSTART.md) · **Українська**

# Швидкий старт

> ⚠️ **Ihor Ivaniuk (@IBITLAB) — ідейник і власник продукту: організовує роботу ШІ, ставить задачі, приймає рішення. Виконавець — ШІ (Claude Code від Anthropic): геометрія, розрахунки, креслення, код і тексти.** Модель, розрахунки й креслення не перевіряв кваліфікований інженер, машину ніхто не будував і не випробовував. Міні-екскаватор калічить і вбиває. Жодних гарантій; автор не несе відповідальності за шкоду життю, здоров'ю чи майну. Усе — на ваш власний ризик і відповідальність. Повне застереження — у [README.uk.md, розділ «Застереження»](README.uk.md#застереження).

Параметрична модель робочого обладнання причіпного міні-екскаватора — стріла, рукоять, важелі, ківш 300 мм — під уже закуплені гідроциліндри. Одна модель OpenSCAD дає STL, креслення (DXF, PDF), специфікацію, розрахунки та інтерактивну 3D-сторінку. Огляд і жива 3D-модель — у [README.uk.md](README.uk.md), подробиці — у [TECHNICAL.uk.md](TECHNICAL.uk.md).

## Що потрібно

| Для чого | Залежність |
|---|---|
| Модель, збирання версій, 3D-сторінка з сервером | **OpenSCAD** — нічна збірка з рушієм Manifold (перевірено на 2025.07 і 2026.09; стабільна 2021.01 не підійде), `openscad` у PATH; **Python 3** |
| PDF-ескізи, звіт ковша | нічого ставити не треба: `tools/.venv` (matplotlib, shapely) створюється сам при першому збиранні |
| 3D-сторінка без бекенду (WASM) | **Node.js ≥ 20.19** |
| Друкований набір і його аркуші розкладки 1:1 (`print3d-parts/make.sh`) | **Chrome** (HTML → PDF) і **poppler** (`brew install poppler`: `pdftoppm`, `pdfinfo`, `pdftotext` — прев'ю та перевірка сторінок із самого PDF; без нього прев'ю робляться знімком HTML) |
| Медіа README: GIF-тур сторінкою і прев'ю PDF (`tools/media/readme_media.sh`) | **ffmpeg**, **poppler**, Chrome і `puppeteer-core` для Node (один раз: `npm i --no-save --prefix tools/media puppeteer-core`; він же ставить номери сторінок у PDF) |
| 3D-миша SpaceMouse (необов'язково) | Chrome / Edge; на macOS драйвер 3Dconnexion на час роботи вимикається — це роблять команди з `:sm` |

## Основні команди

```bash
# відкрити модель: кути стріли / рукояті / ковша — перші параметри в Customizer
openscad scad/excavator_boom.scad

# зібрати версію → versions/VNNN-дата-час/ (STL, рендери, звіти, BOM, DXF, PDF, viewer.html); --commit одразу комітить
tools/build_version.sh --commit "що змінено"

# лише перевірки: пластини не перекриваються / рухомі пари не зіткаються на всьому ході циліндрів
tools/check_overlaps.sh
tools/check_motion.sh

# друкований набір 1:5: STL кожного компонента, перевірки, BOM, аркуші розкладки 1:1 (SHEETS.pdf)
print3d-parts/make.sh

# 3D-сторінка в браузері: кути — миттєво, інші параметри — через OpenSCAD за ≈ 0.4 с
web/viewer.sh

# те саме без бекенду: OpenSCAD-WASM у браузері (перший раз сам зробить npm install)
web/viewer-wasm.sh              # dev-сервер;  build → статичний сайт у dist/;  preview;  test

# зі SpaceMouse на macOS: драйвер вимикається на час роботи сервера і повертається після виходу
tools/dev/with-spacemouse.sh web/viewer.sh
cd web/viewer-wasm && npm run preview:sm
```

Один раз після клонування: `git config core.hooksPath tools/git-hooks` — перевірка перекриттів перед комітом змін моделі.

Результати останнього збирання — у теці `versions/` з найбільшим номером: `drawings/parts.pdf`, `dxf/`, `bom/bom.md`, `docs/`, `viewer.html`.

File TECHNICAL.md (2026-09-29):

**English** · [Українська](TECHNICAL.uk.md)

# Technical details — mini excavator boom, stick and bucket

> ⚠️ **Ihor Ivaniuk (@IBITLAB) is the originator and product owner: organises the AI's work, sets the tasks, makes the decisions. The execution — geometry, calculations, drawings, code and texts — is done by AI (Claude Code by Anthropic).** Not checked by an engineer, never built, never tested. The full disclaimer is in [README.md](README.md#disclaimer); the hazards specific to this design are in [SAFETY.md](SAFETY.md).

The overview, the live 3D model and the PDF documents are in [README.md](README.md). This file holds the details.

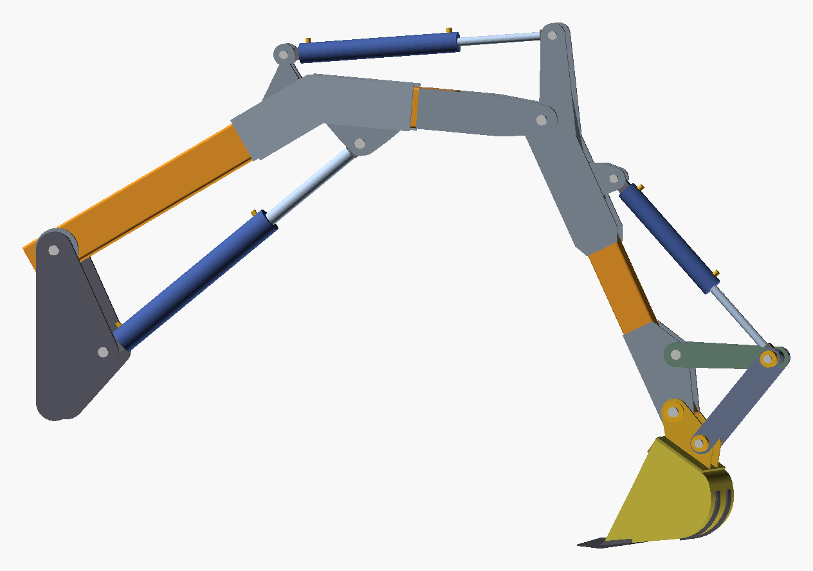
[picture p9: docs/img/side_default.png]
side view


## 1. Files

| File | Purpose |
|---|---|
| `scad/excavator_boom.scad` | **The main model.** All parameters sit at the top of the file (Customizer groups). The angles are the primary parameters; their ranges are derived from the cylinder lengths and printed through `echo()`. |
| `tools/kinematics.py` | An independent solver for the same geometry: range checks, moment arms, tooth force, work envelope; `--search` fits the mounting positions. |
| `tools/work_range.py` | **Working-range drawing** with dimensions A…J (the way excavator catalogues show them): the outline is swept over the full stroke of all three cylinders, the bucket silhouette comes from `tools/bucket.py`. Both languages: `--lang uk\|en`. |
| `views.json` → `tools/views.py` | **Viewpoints saved from the 3D page**: camera, angles, changed parameters, visibility. `list` / `flags` / `render NAME` / `check` (against a real screenshot of the page). A view found by eye becomes a reproducible render. |
| `tools/strength.py` | Member statics plus strength of materials: N/V/M diagrams, checks of the tubes and doublers, pins, bushings and welds; section comparison (`--boom 120x80x5 --stick 100x60x5`). |
| `tools/bucket.py` | **The bucket**: a Python twin of the bucket profile — capacity (struck / heaped), mass, carry and dump angles, a 2D clearance check of the moving pairs over the full stroke, strength of the ears, of pins E/Q and of the welds. Run it with `tools/.venv/bin/python tools/bucket.py [--png file]`. |
| `docs/01-design-inputs.md` | **A source document, written by hand.** The inputs: cylinders, spherical bearings, pins and bushings, the steel sizes actually available, hydraulics, class benchmarks, standards. |
| `docs/research/` | Raw research notes with links to the sources. |
| `docs/img/` | The images used by this README; `build_version.sh` refreshes them from the latest version. |
| `versions/VNNN-date-time/` | **Built versions — everything generated lives only here**: `stl/`, `renders/`, `docs/` (`02-kinematics.md`, `03-strength.md`, `05-bucket.md`, the full logs of the overlap, motion and 3D-page checks), `bom/`, `dxf/`, `drawings/`, `scad/` (a snapshot of the model and the scripts), `VERSION.md`. The current one is the folder with the highest number. |
| `tools/build_version.sh` | **The version build script**: intersection check → moving-pair check → STL of every part → renders → reports → `VERSION.md`. The version number increments automatically. |
| `tools/bom_drawings.sh` | **BOM + drawings**: the bill of materials (`bom.md`, `bom.csv`), the outlines of every plate as 1:1 DXF for cutting, and PDF sketches with the main dimensions (`drawings/parts.pdf` + PNG pages). The data comes from the model's echo and from a projection of each plate — there is no separate list of dimensions anywhere. The first run creates `tools/.venv` with matplotlib. |
| `print3d-parts/` | **The 1:5 printed kit** — every component on its own, the way it is cut from steel (54 files, 76 pieces), glued instead of welded: `make.sh` → STL sorted by slicer job, `BOM.md`, and `sheets/SHEETS.pdf` — **1:1 sorting sheets** for the pile of printed parts: the outline of every part on the sheet of its own sub-assembly, renders with callouts, gluing step cards. See section 2. |
| `web/viewer.sh` → `web/viewer.py`, `web/viewer/index.html` | **An interactive 3D page in the browser**: orbit / pan / zoom, the angles change instantly, and any other model parameter is rebuilt through OpenSCAD in ≈ 0.4 s. See section 2. |
| `web/viewer-wasm.sh` → `web/viewer-wasm/` (`package.json`, Vite) | **A second version of the 3D page — with no backend**: OpenSCAD-WASM in a web worker renders the model right in the browser; it builds into a static site in `dist/`. See section 2. |
| `tools/media/` | **README media**: `readme_media.sh` → the page tour GIF (`page_tour.mjs`, several modes and views) and the PDF previews (`pdf_preview.py`) in `docs/img/`. Screenshots of the page in headless Chrome (`page_shot.mjs`), collages (`compose.py`) and a full set of images and video for publications (`make_media.sh` → `temp/media/`, which is never committed). |
| `tools/check_overlaps.sh` | Checks that the sub-assemblies of the weldment abut but never overlap (the intersection volume of every pair is 0). |
| `tools/check_motion.sh` | Checks the **moving** pairs in 3D over the full cylinder stroke: bucket ↔ stick / rocker / link / cylinder, link ↔ rocker, the bodies of all three cylinders ↔ their own brackets, stick ↔ boom; and, for reference, bucket ↔ boom in the folded pose. |
| `scad/brand/` → `tools/brand_merge.py` | **The logo**: one polygon per size (merged from the generator's output by `brand_merge.py`: ~800 zero-area slivers made every WASM rebuild ≈ 3× slower). Where it goes is the `brand_marks` table in the model — the 3D pages, the renders, the sheets and the printed recesses all read that one table. |
| `tools/page_style.py` | **One look for every PDF**: the header (bold title, "kit · version · date", a 0.5 mm rule) and the footer (document · author · date · page N/M) of `SHEETS.pdf` and the part sketches. |
| `tools/check_personal.py` | **Before every commit**: the staged changes are searched for personal data — the added text and the metadata inside binaries (PDF, PNG text chunks, zip-based files such as `.3mf`). The machine-specific patterns (home folder, user name, git e-mail) are read at run time; none of them is stored in the script. |
| `tools/check_docs.py` | After editing the docs: every relative link and image leads to an existing file, every `#anchor` to a real heading, and the English/Ukrainian twins (README, TECHNICAL, QUICKSTART, SAFETY) have the same skeleton. |
| `tools/stl_volume.py` | The volume of an STL (cm³), needed for the intersection check. |
| `tools/dev/agent_analytics.py` | Analytics of the agent work from the Claude Code logs (tokens, minutes, roles). |
| `tools/git-hooks/pre-commit` | A git hook: before committing changes under `scad/` it checks the plates for overlaps. Enable it once: `git config core.hooksPath tools/git-hooks`. |
| `CLAUDE.md` | Project rules for Claude Code (language, commits, where everything lives). |
| `.claude/skills/` | The project skills: `scad-mechanism` (model rules and checklist), `new-assembly` (the recipe for a new sub-assembly), `build-version`, `part-drawings`, `browser-verify` (checking the pages in headless Chrome), `media-kit` (material for publications), `print-kit` (the 1:5 printed kit), `print-sheets` (the 1:1 sorting sheets), `design-review`, `research-sweep`, `agent-analytics`. Everything stays inside the repository; nothing is installed into `~/.claude`. |
| `.claude/workflows/` | Saved multi-agent workflows: `design-review` (reviewers + refutation) and `research-sweep` (researchers + a critic). Every agent writes its result straight into `docs/reviews/…` or `docs/research/…`, so nothing is lost if a usage limit cuts the run short. |

Agreement between the two independent implementations (OpenSCAD ↔ Python): the angle ranges match to within 0.1°, the bucket-linkage branch to 0.000 mm.

## 2. Using the model

Open `scad/excavator_boom.scad` in OpenSCAD (≥ 2021.01; verified on 2026.09). The first group in the Customizer (Window → Customizer):

| Parameter | Default | Range (computed) | Meaning |
|---|---|---|---|
| `boom_angle` | 15° | **−38.1° … +58.3°** | angle of the boom chord (axis A → axis B) to the horizon, + upwards |
| `stick_angle` | 100° | **50.7° … 155.6°** | interior boom–stick angle at joint B (folded … extended) |
| `bucket_angle` | 60° | **−17.0° … +138.5°** | bucket angle relative to the stick axis, + = curling in |
| `clamp_to_cylinders` | true | | limit the angles to what the cylinders can reach (otherwise: a red cylinder + a warning) |

The console (`echo`) prints the ranges, the current cylinder lengths and moment arms, and the tooth coordinates. The remaining groups are: cylinders (closed length, stroke, barrel/rod, pin), boom, stick, bucket linkage, pins/bushings/plates, and display (`show_envelope` draws the work envelope as points).

From the command line:
```
openscad -o out.png --viewall --autocenter -D boom_angle=-38 -D stick_angle=90 -D bucket_angle=60 scad/excavator_boom.scad
openscad -o out.echo scad/excavator_boom.scad        # just the echo with the ranges
cd tools && python3 kinematics.py && python3 strength.py --boom 120x80x5 --stick 100x60x5
```

### The interactive 3D page (Step 2.0)

```
web/viewer.sh                                   # opens http://127.0.0.1:8765/ in the browser (Ctrl+C to stop)
python3 web/viewer.py --export file.html        # a static page with no server (one ships with every version: versions/VNNN-…/viewer.html)
```

- **Mouse**: left button orbits, right button or Shift pans, the wheel zooms towards the cursor, a double click on a part sets a new orbit centre. There are view buttons (side, isometric, top, front, fit) and a perspective / orthographic toggle.
- **The boom, stick and bucket angles** move the model instantly: the page assembles the pose itself, using the same formulas as the model's `pt_*()` functions and the points the model prints in `echo(VIEW = …)` (cross-checked against the model's echo: the tooth position and the cylinder lengths agree to within 0.1 mm). The slider limits come from the cylinder strokes; next to each angle you see the cylinder length and the stroke used. Clear "limit to cylinder stroke" and a cylinder beyond its stroke turns red. Ready-made poses and a "dig cycle" are included.
- **Every other parameter** (the Customizer groups are read straight from the `.scad` — there is no separate list) goes to a local server: it runs OpenSCAD in parallel for 12 parts in their own coordinate frames and returns coloured meshes (OFF format). Changed parameters are highlighted; "Copy changes" gives you lines ready to paste into the `.scad`; "Reload model" picks up edits to the file. Warnings from the model (`!!!` — a dead centre in the linkage, an unreachable cylinder length) are shown on screen.
- The server listens on 127.0.0.1 only; values coming from the browser are coerced to the types in the schema (numbers, booleans, enumerations), so arbitrary text never reaches OpenSCAD. three.js is loaded from a CDN (jsdelivr) — an internet connection is required.

### The 3D page with no backend: OpenSCAD-WASM in the browser (Step 2.1)

```
cd web/viewer-wasm && npm install      # dependencies: three, openscad-wasm-prebuilt (OpenSCAD 2025.01 + Manifold, 11 MB), vite
npm run dev                              # http://localhost:8766/ — editing scad/excavator_boom.scad reloads the page at once
npm run build                            # a static site in dist/ (≈12 MB): drop it on any static host
npm run preview                          # view the built dist/ locally
npm test                                 # a smoke test with no browser
# the same in one command from the repository root: web/viewer-wasm.sh [build|preview|phone|test]
# phone — build and serve it to your phone on the same Wi-Fi (Vite otherwise listens on 127.0.0.1 only)
```
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

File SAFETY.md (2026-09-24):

**English** · [Українська](SAFETY.uk.md)

# Safety: the known hazards of this particular design

> ⚠️ **Ihor Ivaniuk (@IBITLAB) is the originator and product owner: organises the AI's work, sets the tasks, makes the decisions. The execution — geometry, calculations, drawings, code and texts — is done by AI (Claude Code by Anthropic).** None of it has been checked by a qualified engineer, and no machine has ever been built or tested from this model. The full disclaimer is in [README.md, section Disclaimer](README.md#disclaimer). Whatever you do with this material, you do at your own risk and on your own responsibility.

This file is not general advice about being careful. It is a list of **the specific places where this design is currently unfinished or rests on assumptions**. It exists so that you do not find out about them through an injury.

## 1. Gaps that must be closed while you are still doing the hydraulics

| Hazard | What exactly is wrong | What to do |
|---|---|---|
| **The boom drops when a hose fails** | The design has **no load-holding valves** (lock valves, hose-burst valves). If a boom cylinder hose bursts or blows off under load, the boom and bucket come down at whatever speed the oil can escape. This is exactly how people are killed — standing or working under a raised boom. | Fit hose-burst / load-holding valves directly onto the boom and stick cylinders. Until they are there, **never go under a raised boom**, and prop it mechanically for any maintenance. |
| **Overpressure in a closed cylinder** | The Z50 valve has **no port relief valves**. Under an external load (a shock through the bucket, ground settling, a lever effect from the tooth) a closed boom cylinder can see **250–335 bar** instead of the 160–180 bar working pressure. The calculation accounts for this, but the safety factor at the worst section drops to 1.52. | An external block of cross-over relief + anti-cavitation valves (G3/8, 220–250 bar) on the boom cylinder lines. Set the main relief to 160–180 bar. |
| **A pinhole jet of hydraulic oil** | A pinhole in a hose produces a thin, invisible jet that **penetrates skin** and injects oil into the tissue. It looks like a small dot and hurts only moderately — and a few hours later it is an amputation if it is not operated on. | Never search for a leak with your hand or a finger — use a piece of cardboard. Release the pressure before dismantling anything. If you suspect an injection, **go to a surgeon immediately** and say it is pressurised hydraulic oil. |

## 2. The assumptions the calculations rest on

- **The mass of the machine is unknown.** The stability cap `F_STAB` in `tools/strength.py` is set to **15 kN, which is a guess**. The real forces and the tipping moment depend on the mass and wheelbase of the trailer. Without that number the vertical load cases are **meaningless**. Recompute after weighing it.
- **The cylinder lengths are nominal.** 700 / 600 / 510 mm come from the vendor description, which says "≈". The real pin-to-pin lengths must be **measured** and entered: every angle range and every clearance depends on them.
- **The boom cylinder eye size is a guess.** ШС-30 was inferred from comparable parts. If it turns out to be Ø25, then `boom_cyl_pin` and `pin_A` change, and clevis D with them.
- **The side force at the tooth is taken as 3 kN.** That is an estimate for swinging the column with the bucket in the ground. The real value depends on a swing mechanism that does not exist yet.
- **The bucket lip clearance is 7 mm** at +4° of cylinder over-travel. If the real extended length of the bucket cylinder exceeds 810 mm, the lip may reach the stick. Check with `tools/bucket.py`.

## 3. What the model does not check at all

- **The swing column is schematic** and is part of no check whatsoever — neither strength nor collision.
- **The moving pairs are checked at discrete positions** (13 bucket angles, 12 stick, 8 boom), not continuously. Between the checked points a collision is theoretically possible.
- **The fit between plates has only been checked visually** on the renders; the only thing checked numerically is that parts do not overlap.
- **Pin retention and grease nipples were deliberately deferred.** A pin that walks out of a clevis under load means that member collapses. Work out the retention (split pins, keeper plates, circlips) before you lift anything for the first time.
- **There is no operator protection**: no ROPS/FOPS, no guarding, no emergency pressure dump, no lockout against accidentally knocking a control lever.
- **Fatigue was not calculated.** Every check is static. An excavator works in cycles, and welds fail by fatigue at stresses far below the yield point.

## 4. Materials you must not economise on

- **The bucket cutting edge and teeth must be wear-resistant steel only** (Hardox 400/450, 65Г, a grader blade). Mild steel on the edge wears away in hours, and a mild-steel tooth bends and tears off.
- **The boom tube must not be rimming steel (Ст3кп).** Rimming steel is brittle in the cold and welds badly. Ask for a certificate: Ст3сп/пс or S235JRH.
- **The joint between the two boom segments** sits in the zone of the highest moment. It needs bevelled edges and **full penetration**, otherwise the weld will open under load. This is work for a certified welder, not a few tacks with a MIG gun.
- **The pins** must be king pins in induction-hardened 45Х or tempered 40Х. A pin in plain mild steel will shear.

## 5. The minimum before you lift anything with this machine

1. A qualified mechanical engineer has reviewed the calculations and the drawings.
2. A certified welder did the welding, and the critical welds have been inspected.
3. A specialist assembled the hydraulics; load-holding valves and overpressure protection are in place.
4. Every pin is retained, every joint has a grease nipple and has been greased.
5. The first load is taken on the ground, gradually, **with nobody within reach of the boom**.
6. Before every start-up, inspect the welds at the stick root, near base H and in the boom break zone: those are the places with the smallest margin.

## 6. If something turns out to be wrong

Nothing in this repository is grounds for treating the design as verified. If you find an error in a calculation or a drawing, fix it in the model and rebuild the version; do not edit the generated files by hand.

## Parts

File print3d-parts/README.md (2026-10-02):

# Набір компонентів під зварювання, 1:5

Кожна деталь машини окремо — так, як її ріжуть з металу: **три профільні труби,
двадцять пластин, накладок, сідел і ребер, обичайка ковша, ніж, зуби, смуги
зносу, десять втулок і бобишок, одинадцять пальців, три робочі гідроциліндри**. Разом 54 файли,
76 штук. Складається склеюванням — там, де в металі був би шов.

> **УВАГА.** Автор — Ihor Ivaniuk (@IBITLAB): ідея, задачі, рішення; модель, розрахунки
> й ця підготовка до друку зроблені ШІ (Claude Code). Інженер їх не перевіряв, метал не
> різаний, машина не збудована.
> Надрукований набір — демонстрація складу конструкції, а не документація й не
> іграшка. Пальці Ø4.6–5.6 мм — дрібні деталі, не для дітей. Див. `SAFETY.md`.

```
print3d-parts/make.sh "що змінено"   # ≈1 хв: нова підверсія набору в latest/print3d/
```

Тут лише джерела: склад — `parts.tsv`, кроки — `assembly.tsv`, обгортка — `parts.scad`.
Усе зібране лежить у [latest/print3d/](../latest/print3d/) — підверсія `VNNN.K` набору
машини `VNNN`: нова версія машини збирає набір `VNNN.1` сама (`tools/build_version.sh`),
зміна лише набору — `make.sh`, і попередня підверсія переїжджає в `latest/print3d-history/`.
Набір збирається тільки з тієї моделі, що в `latest/scad/`: змінилась модель — спершу версія машини.
Специфікація з виміряними габаритами — [BOM.md](../latest/print3d/BOM.md).

STL розкладено по теках — **одна тека = одне завдання слайсера**; назва каже колір, висоту
шару й підпори (склад груп — `group.sh`):

| Тека | Що | Шар | Підпори |
|---|---|---|---|
| `1_body_yellow_0.20mm_no-supports` | труби, пластини, накладки, вилки, ківш — корпусний жовтий | 0.20 | **вимкнути**: «всюди» заллє нутро труб |
| `2_wear_dark_0.20mm_brim` | ніж, зуби, смуги зносу — зносостійка сталь, темний | 0.20 | ні; brim |
| `3_cylinders_grey_0.20mm_supports-from-bed` | гільзи й штоки гідроциліндрів, сірий | 0.20 | **лише від столу** |
| `4_bushings-bosses_silver_0.12mm_brim` | втулки, бобишки, шайби — сріблястий | 0.12 | ні; brim |
| `5_pins_silver_0.12mm_brim` | пальці — сріблястий | 0.12 | ні; brim |

**Розібрати купу надрукованого** — [SHEETS.pdf](../latest/print3d/sheets/SHEETS.pdf): шість аркушів
A4 з контурами деталей **1:1**, по аркушу на кожен вузол, що склеюється, і окремий для
пальців та шайб. Деталь кладеться на свій контур; біля нього — номер кроку, файл,
габарити й отвори; у вільному місці — рендери вузла з виносками, далі — картки кроків
склеювання. Як це зроблено — [sheets/README.md](sheets/README.md).

## Перерахунок масштабу

Найбільший ОКРЕМИЙ компонент — не стріла, а труба рукояті, 1050 мм (стріла ділиться
на два сегменти по 1008.9 і 598.9 мм). Тому масштаб більший, ніж у зварного набору:

| Масштаб | Труба рукояті | Влазить у 250 |
|---|---:|---|
| 1:4 | 262.5 мм | ні |
| **1:5** | **210.0 мм** | **так, запас 40 мм** |

Виграш від 1:5 проти 1:7 — усі стінки стають придатними:

| Елемент | У металі | 1:5 | (було 1:7) |
|---|---:|---:|---:|
| стінка труби | 5 мм | **1.00 мм** | 0.71 |
| обичайка ковша | 5 мм | **1.00 мм** | 0.71 |
| боковина ковша | 6 мм | 1.20 мм | 0.86 |
| щока | 8 мм | 1.60 мм | 1.14 |
| накладка | 10 мм | 2.00 мм | 1.43 |
| вилка, ніж | 12 мм | 2.40 мм | 1.71 |
| упорна шайба осі B | 2 мм | 0.40 мм | 0.29 — не друкувалася |

Нічого тоншого за сопло не лишилося. Шайба осі B рівно в одну лінію — два шари
по 0.2 мм; на 1:7 вона була тонша за шар і в набір не входила.

## Орієнтація: чому одного правила не вистачило

У наборі зварних вузлів усе клалося за одним правилом «вісь Y моделі догори» — там
друкуються цілі вузли, і воно спрацювало. Тут — ні, і на цьому спіймано дві різні вади.

**Перша: «товщина», яка насправді ширина.** Пластини вузлів задані як
`plate_xz(pts, t, y0)` з `t` = товщина листа. Але смуги зі списку `BOM_STRIPS`
описані тим самим модулем, де `t` = **ширина** деталі: у сідла H це 60 мм, а справжні
10 мм лежать у профілі. З «Y догори» така смуга стає на ребро — накладка ковша
виходила 1.6 × 34 × 60 мм, тобто лезо, яке впаде зі столу. Тому вісь задається на
деталь, у колонці `вісь` файлу `parts.tsv`, і кожна звірена обміром усіх трьох
варіантів.

**Друга: деталі, нахилені у вузлі.** Ніж ковша, сідло D, ребро п'яти й накладка
перелому стоять у своїх вузлах під кутом, і жодна з трьох осей не кладе їх плазом:
ніж виходив баштою 60 мм заввишки на основі 15 × 15 мм із контактом 44 мм².

Кут для них не підбирався на око, а порахований: у STL деталі береться сумарна площа
граней за напрямком нормалі, найбільша грань — це і є та, що має лягти на стіл, а кут
повороту навколо Y дорівнює `atan2(nx, −nz)` її нормалі. Усі ці деталі призматичні
вздовж Y (складова `ny` найбільшої нормалі ≈ 0), тому повороту навколо однієї осі
досить. Результат — у колонці `поворот`:

| Деталь | Найбільша грань | Поворот | Було | Стало |
|---|---:|---:|---|---|
| ніж ковша | 30000 мм² (300×100) | 130.01° | 14.7×15.3×60, низ 44 | **20×60×2.4, низ 1200** |
| сідло D | 20800 мм² | 160.24° | 49.6×19.5×16, низ 104 | **52×16×2, низ 832** |
| ребро п'яти | 18654 мм² | 166.64° | 61×14.4×12, низ 116 | **62.2×12×2, низ 746** |
| накладка перелому | 13715 мм² | 160.24° | 65.3×13.1×16, низ 109 | **62.4×16×21, низ 549** |

Зуб ковша теж нахилений, але для нього поворот дав **гірше** — 24.8 % полиць замість
нуля, бо він клиноподібний і його найбільша грань тягне за собою звис із іншого боку.
Тому зуб лишився як був. Порахований кут — підказка, не вирок; перевіряти все одно
обміром.

## Деталі в повітрі

Після орієнтації **46 з 54 компонентів друкуються без жодної підпори** (0 % полиць).
Лишилися дві групи (і ще плита колони, 1.5 % — це виїмка бренду з боку столу, див. «Бренд»):

**Труби, 14 %.** Це не звис, а стеля порожнистої труби. Переріз надрукованого STL
показує метал лише на −6.00…−5.00 і 5.00…6.00: стінки рівно 1.00 мм, між ними
порожнина. Стеля спирається на обидві стінки, тобто це **місток 18 мм** (рукоять) і
**22 мм** (стріла), який FDM кладе без підпор.

> **Підпори — тільки «від столу» (support on build plate only).**
> Підпора «всюди» заповнить нутро труб, а дістати її звідти неможливо: труба закрита
> з усіх боків, і на відміну від зварного набору тут вона ще й найдовша деталь.

**Гільзи й шток циліндра, 7–9 %.** Горизонтальний циліндр із плоским вушком: дрібні
полиці на 0–11 мм над столом. Підпора від столу їх бере.

Найменший контакт зі столом у наборі — 27 мм² (розпірна втулка осі G, Ø7.8 мм).
Для неї, для пальців і для обичайки ковша давайте brim.

**Обичайка ковша** (`18_bk_shell`) друкується поставлена на профіль: кожен шар — та
сама крива, **нуль звисів і нуль схилів**, найчистіший друк у наборі. Ціна — стінка
1 мм заввишки 57.6 мм стоїть на 112 мм² контакту. Brim обов'язковий. Варіант «покласти
фланцем на стіл» дає 2094 мм² контакту, але 1887 мм² схилів 20–45° на стінці 1 мм —
вона провисне, тому не він.

## Посадки й рухомі циліндри

Жоден отвір у моделі не перероблявся — **увесь зазор знятий із пальця** (`FIT_PIN`,
0.40 друкованих мм). Пальці Ø30 → **5.60 мм**, Ø25 → **4.60 мм**. Навпаки — зазор в
отворах — довелося б розточувати кожен отвір у кожному вузлі за його локальними
координатами: десятки місць і тихі помилки, а модель для металу мала б лишитися незмінною.

Втулки й бобишки друкуються в номінал і вклеюються у свої отвори — тут це не посадка,
а шов: у металі вони вварені.

Гільзи мають глухий канал Ø(шток + 0.35): циліндри ходять. Канал стріли 8.35 мм,
решта 5.35 мм.

## Привід циліндрів гвинтом M5

Оберти гайки M5×0.8, за яких циліндри моделі ходять за час машини, момент і потужність
моторедуктора під вагу набору та вибір серед N20 — у [latest/print3d/DRIVE.md](../latest/print3d/DRIVE.md).
Його генерує `model_drive.py` під час `make.sh` з виміряних STL; припущення (витрата, тертя,
заповнення, маса приводу) — сталі на початку скрипту.

Самі робочі циліндри на шпильці M5 спроєктовано в [m5_cylinders/](m5_cylinders/README.md):
- гайка крутиться в шестерні в голові циліндра, збоку стоїть моторедуктор N20;
- енкодер і кінцевики — на датчиках Холла;
- зведена довжина й хід такі самі, як у моделі.

Це окремі деталі поруч із «глухими» циліндрами набору, у `parts.tsv` їх немає. Збирає їх той самий
`make.sh`, результат — у [latest/print3d/m5_cylinders/](../latest/print3d/m5_cylinders/): STL, рендери,
`CALC.md` (час ходу вибраного мотора, сили, маса), `WIRING.svg` (схема підключення) і `SENSORS.svg` (як ставити датчики Холла).

## Важливе, що цей набір НЕ дає

- **Це не розкрій.** Деталі друкуються у **кінцевій формі, вже гнутими** — обичайка
  ковша скручена, накладка перелому зігнута на 35°, смуги зносу вигнуті по радіусу
  п'яти. Пласкі заготовки під різання — це DXF у `latest/dxf/`.
- **Немає кондуктора.** У зварному наборі стріла — одне тіло, тут її треба зібрати з
  десятка пластин на око. Орієнтуйся на ескізи в `latest/drawings/parts.pdf` і на
  інтерактивну 3D-сторінку.
- **Print-in-place не застосовано свідомо**: палець, надрукований усередині втулки,
  вимагає підпор там, куди вже не дістатися, а зазор 0.4 мм на Ø5 мм дав би або
  злиплий шарнір, або бовткий. Окремі пальці дають і кращий шарнір, і розбірність.

## Друк

| | |
|---|---|
| сопло | 0.4 мм |
| шар | 0.2 мм; 0.12 для пальців, втулок і бобишок |
| периметри | 3 |
| заповнення | 15–20 % |
| підпори | **тільки від столу** |
| brim | труби, обичайка ковша, пальці, втулка G |
| матеріал | PLA або PETG; 190 см³ ≈ 236 г при 100 %, реально близько 100–120 г |

Гільзи циліндрів складаються з трьох тіл, що прилягають гранями (так побудована
модель: «пластини прилягають, але не перетинаються»). Слайсер зливає їх при
нарізанні; у Cura ввімкніть *Union overlapping volumes*.

**Бренд.** На обох бічних стінках труби стріли (сегмент 1) і труби рукояті, на обох гранях
плити колони та на зовнішній грані кожної боковини ковша є виїмка 0.4 мм зі знаком
(на трубах і боковинах — ще й зі словом). Місця беруться з моделі (розділ «ЛОГОТИП»,
таблиця `brand_marks`, полігони в `scad/brand/`) — там само, де знак видно на 3D-сторінках
і рендерах; `brand.scad` тут лише вирізає виїмку. Виїмка друкується без жодних
налаштувань: усі її штрихи й стінки між ними не тонші за 0.8 мм, тобто дві лінії сопла.
На трубах і плиті одна з граней друкується на столі — там виїмка вийде трохи грубішою
через розплющення першого шару, це нормально (звідси й 1.5 % «полиць» у плити). Модель і
місця накладних деталей від цього не змінилися: виїмки стоять у вільних зонах між ними.
Через логотип боковини ковша — два РІЗНІ файли, `19_bk_side_L` і `19_bk_side_R`: у металі це
одна деталь ×2, а тут ліва й права дзеркальні, і знак на кожній має бути назовні. Обидві
друкуються знаком догори; рядок іде паралельно дну ковша. На аркушах розкладки знак
намальований на контурі — так, як деталь лежить на папері.

## Порядок складання

Що до чого приклеюється — картки кроків у [SHEETS.pdf](../latest/print3d/sheets/SHEETS.pdf): сім
вузлів (стріла, рукоять, ківш, важільна система, колона, циліндри, пальці), 54 кроки, у
кожному — куди деталь стає і за чим орієнтуватися. Порядок той самий, що й порядок
зварювання в металі. Вузли 1–5 склеюються, пальці 7 лишаються рухомими. Схожі деталі
позначені просто біля контуру: «= однакові», «дзеркальна до …», «≈ … чим різняться» —
обміром STL, тобто реальна, а не задумана різниця.

Джерело порядку — `assembly.tsv`; `make.sh` зупиниться, якщо якась деталь набору
лишилася без кроку складання (інакше вона мовчки випала б з аркушів).

## Як це зроблено

`parts.scad` підключає `scad/excavator_boom.scad` як бібліотеку з `part="none"` і
дістає компоненти **механізмом самої моделі**: `$sel` лишає одну деталь вузла, `$one` —
одну з дзеркальної пари. Тому геометрія тут рівно та, що піде в цех.

Винятки, де компонент будується в обгортці, а не дістається:

- **круглі** (втулки, бобишки, розпірки, шайба) — у тяги `link_boss` стоїть у
  подвійному циклі `for (s = sides()) for (P = [J, Q])`, і `$one` прибирає лише
  дзеркало: лишаються дві бобишки в різних місцях замість однієї. Тому всі кільця
  будуються з тих самих виразів; числа звірені з `echo(BOM_ROUND)` моделі;
- **труби** — беруться через `tube_local()`, той самий модуль, що дає розгортки для
  ескізів: він ставить трубу віссю вздовж +X;
- **пальці й плити колони** — у моделі намальовані всередині `assembly()` і
  `post_schematic()`, окремими модулями їх немає;
- **гільзи циліндрів** — у моделі корпус суцільний, канал під шток свердлиться тут.

Джерела набору лежать тут, а зібране — у `latest/print3d/`: набір — частина версії
машини й архівується разом із нею. Перевірка `check_print.py` і генератор `make_bom.py`
лежать тут же — набір самодостатній. `DRIVE.md` (привід M5) пише `model_drive.py` (крок
`make.sh`, або окремо `python3 print3d-parts/model_drive.py --print`): циліндри й кінематику
він бере з `tools/kinematics.py`, місткість ковша — з `tools/bucket.py` (через
`tools/.venv`), масу — з щойно зібраних STL.

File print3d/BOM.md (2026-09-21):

# Специфікація друкованого набору 1:7

> Згенеровано `make.sh` з **виміряних** STL — руками тут нічого не вписано.
> Модель-джерело: `scad/excavator_boom.scad`, версія геометрії `V001-2026-09-20-0505`.
>
> **УВАГА:** це масштабна модель, згенерована штучним інтелектом. Вона не є ні
> проєктною документацією, ні іграшкою, ні тренажером: метал не різаний, машину
> не збудовано й не випробувано. У наборі є деталі від 11 мм — не для дітей.
> Див. `SAFETY.md`.

**Усього:** 30 друкованих деталей, 27 різних файлів, 69.0 см³ суцільного об'єму (≈ 86 г PLA при 100 % заповненні; при звичайних 20 % і 2 периметрах — приблизно вдвічі менше).

## Несучі вузли

| Файл | К-сть | Габарит XYZ, мм | Об'єм, см³ | Низ, мм² | Полиці | Опис |
|---|---:|---|---:|---:|---|---|
| `01_post_plate_x2.stl` | 2 | 35.7 × 80.0 × 1.7 | 3.27 | 1905 | — | Плита поворотної колони — осі A (стріла) і C (база циліндра стріли) |
| `02_boom_x1.stl` | 1 | 239.2 × 71.3 × 14.9 | 17.83 | 937 | 27.1% (12.5 мм, 1.5 мм) | Стріла у зборі: труби, щоки перелому, вилка B, вежа F, вилка D, гніздо втулки A |
| `03_stick_x1.stl` | 1 | 178.8 × 34.1 × 11.4 | 11.33 | 727 | 27.7% (9.5 мм, 0.5 мм) | Рукоять у зборі: труба, щоки п'яти, вилка H, накладки кінця, гнізда втулок B, E, R |
| `04_bucket_x1.stl` | 1 | 74.5 × 46.1 × 42.9 | 9.61 | 1266 | 12.0% (42 мм, 27.5 мм) | Ківш у зборі: обичайка, боковини, ніж, 3 зуби, вуха осей E і Q, смуги зносу |

## Важільна система

| Файл | К-сть | Габарит XYZ, мм | Об'єм, см³ | Низ, мм² | Полиці | Опис |
|---|---:|---|---:|---:|---|---|
| `05_rocker_plate_x2.stl` | 2 | 51.2 × 10.6 × 5.4 | 0.72 | 462 | — | Пластина коромисла з бобишкою осі J (осі R і J) |
| `06_link_plate_x2.stl` | 2 | 56.0 × 9.3 × 5.0 | 0.90 | 480 | — | Тяга ковша з бобишками осей J і Q |

## Гідроциліндри

| Файл | К-сть | Габарит XYZ, мм | Об'єм, см³ | Низ, мм² | Полиці | Опис |
|---|---:|---|---:|---:|---|---|
| `07_cyl_boom_body_x1.stl` | 1 | 93.4 × 12.9 × 10.9 | 5.66 | 235 | 6.9% (8.5 мм, 0 мм) | Гільза циліндра стріли Ø63 з каналом під шток |
| `08_cyl_boom_rod_x1.stl` | 1 | 89.1 × 8.3 × 5.7 | 2.23 | 176 | 3.2% (1 мм) | Шток циліндра стріли Ø40 |
| `09_cyl_stick_body_x1.stl` | 1 | 78.8 × 10.6 × 8.6 | 3.38 | 154 | 7.1% (6 мм, 0 мм) | Гільза циліндра рукояті Ø50 з каналом під шток |
| `10_cyl_stick_rod_x1.stl` | 1 | 74.5 × 7.6 × 3.6 | 0.82 | 171 | — | Шток циліндра рукояті Ø25 |
| `11_cyl_bucket_body_x1.stl` | 1 | 65.9 × 10.6 × 8.6 | 2.82 | 125 | 7.2% (0 мм, 6 мм) | Гільза циліндра ковша Ø50 з каналом під шток |
| `12_cyl_bucket_rod_x1.stl` | 1 | 60.2 × 7.6 × 3.6 | 0.68 | 144 | — | Шток циліндра ковша Ø25 |

## Втулки

| Файл | К-сть | Габарит XYZ, мм | Об'єм, см³ | Низ, мм² | Полиці | Опис |
|---|---:|---|---:|---:|---|---|
| `13_bush_A_x1.stl` | 1 | 9.4 × 9.4 × 20.0 | 1.11 | 55 | — | Втулка осі A — стріла на колоні (в моделі Ø66/30×140) |
| `14_bush_B_x1.stl` | 1 | 9.4 × 9.4 × 10.9 | 0.60 | 55 | — | Втулка осі B — стріла–рукоять (Ø66/30×76) |
| `15_bush_E_x1.stl` | 1 | 9.4 × 9.4 × 11.4 | 0.63 | 55 | — | Втулка осі E — рукоять–ківш (Ø66/30×80) |
| `16_bush_R_x1.stl` | 1 | 6.4 × 6.4 × 11.4 | 0.21 | 18 | — | Втулка осі R — коромисло (Ø45/30×80) |

## Пальці

| Файл | К-сть | Габарит XYZ, мм | Об'єм, см³ | Низ, мм² | Полиці | Опис |
|---|---:|---|---:|---:|---|---|
| `17_pin_A_x1.stl` | 1 | 5.5 × 5.5 × 26.5 | 0.33 | 24 | — | Палець осі A — стріла на колоні |
| `18_pin_C_x1.stl` | 1 | 5.5 × 5.5 × 26.5 | 0.33 | 24 | — | Палець осі C — база циліндра стріли в плитах колони (довжина як у пальця A) |
| `19_pin_B_x1.stl` | 1 | 5.5 × 5.5 × 18.8 | 0.23 | 24 | — | Палець осі B — стріла–рукоять |
| `20_pin_D_x1.stl` | 1 | 5.5 × 5.5 × 11.1 | 0.14 | 24 | — | Палець осі D — шток циліндра стріли у вилці стріли |
| `21_pin_E_x1.stl` | 1 | 5.5 × 5.5 × 21.9 | 0.27 | 24 | — | Палець осі E — рукоять–ківш |
| `22_pin_F_x1.stl` | 1 | 4.8 × 4.8 × 10.6 | 0.09 | 18 | — | Палець осі F — база циліндра рукояті на стрілі |
| `23_pin_G_x1.stl` | 1 | 4.8 × 4.8 × 14.2 | 0.12 | 18 | — | Палець осі G — шток циліндра рукояті на п'яті рукояті |
| `24_pin_H_x1.stl` | 1 | 4.8 × 4.8 × 10.6 | 0.09 | 18 | — | Палець осі H — база циліндра ковша на рукояті |
| `25_pin_J_x1.stl` | 1 | 4.8 × 4.8 × 28.8 | 0.24 | 18 | — | Палець осі J — шток циліндра ковша, коромисло і тяги |
| `26_pin_Q_x1.stl` | 1 | 4.8 × 4.8 × 28.8 | 0.24 | 18 | — | Палець осі Q — тяги і вуха ковша |
| `27_pin_R_x1.stl` | 1 | 5.5 × 5.5 × 15.1 | 0.19 | 24 | — | Палець осі R — коромисло на кінці рукояті |

## Позначення

- **Низ** — площа, якою деталь лежить на столі. Менше ~20 мм² — обов'язковий brim.
- **Полиці** — частка площі, що друкується в повітрі майже горизонтально, і висота
  найбільших над столом. Дужки з висотою 0.5–1.5 мм означають підсічки під
  пластинами: підпора зі столу їх бере. Полиці всередині труб — це містки, не звиси
  (див. README), підпору туди пускати НЕ можна.
- Габарити — уже в друкованих міліметрах, деталі повернуті в позу друку.

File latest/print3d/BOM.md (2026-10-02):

# Специфікація компонентів під зварювання 1:5

> Згенеровано `make.sh` з **виміряних** STL — руками тут нічого не вписано.
> Модель-джерело: `scad/excavator_boom.scad`, набір `V006.2`.
>
> **УВАГА:** це масштабна модель. Автор — Ihor Ivaniuk (@IBITLAB): ідея, задачі, рішення; виконання — ШІ (Claude Code).
> Інженер не перевіряв. Модель не є ні проєктною документацією, ні іграшкою, ні тренажером:
> метал не різаний, машину не збудовано й не випробувано. У наборі є деталі від 8 мм — не для дітей.
> Див. `SAFETY.md`.

**Усього:** 76 друкованих деталей, 54 різних файлів, 189.5 см³ суцільного об'єму (≈ 235 г PLA при 100 % заповненні; при звичайних 20 % і 2 периметрах — приблизно вдвічі менше).

## Профільні труби

| Файл | К-сть | Габарит XYZ, мм | Об'єм, см³ | Низ, мм² | Полиці | Ескіз | Опис |
|---|---:|---|---:|---:|---|---|---|
| `01_tube_boom_seg1_x1.stl` | 1 | 201.8 × 24.0 × 16.0 | 14.19 | 4049 | 14.8% (15 мм, 0.5 мм) | [с. 3](../drawings/parts.pdf#page=3) | Стріла, сегмент 1: труба 120×80×5, торець 90°, косий різ 17.5°, отвір Ø66 під втулку A |
| `02_tube_boom_seg2_x1.stl` | 1 | 119.8 × 24.0 × 16.0 | 7.41 | 2247 | 14.2% (15 мм) | [с. 4](../drawings/parts.pdf#page=4) | Стріла, сегмент 2: труба 120×80×5, косий різ 17.5°, скіс торця (верхня полиця коротша на 160) |
| `03_tube_stick_x1.stl` | 1 | 210.0 × 20.0 × 12.0 | 11.41 | 3453 | 14.8% (11 мм, 0.5 мм) | [с. 5](../drawings/parts.pdf#page=5) | Рукоять: труба 100×60×5, отвори Ø66 під втулки B і E, фаски переднього торця 25×25 |

## Стріла

| Файл | К-сть | Габарит XYZ, мм | Об'єм, см³ | Низ, мм² | Полиці | Ескіз | Опис |
|---|---:|---|---:|---:|---|---|---|
| `04_gusset_x2.stl` | 2 | 113.1 × 48.1 × 1.6 | 4.93 | 3080 | — | [с. 7](../drawings/parts.pdf#page=7) | Щока перелому стріли, лист 8 мм |
| `05_cover_x1.stl` | 1 | 62.4 × 16.0 × 21.0 | 1.74 | 549 | — | — | Верхня накладка перелому, 8 мм — гнути посередині на 35° |
| `06_D_clevis_x2.stl` | 2 | 41.4 × 24.2 × 2.4 | 0.99 | 411 | — | [с. 8](../drawings/parts.pdf#page=8) | Вилка D (шток циліндра стріли), лист 12 мм |
| `07_D_saddle_x1.stl` | 1 | 52.0 × 16.0 × 2.0 | 1.66 | 832 | — | — | Сідло вилки D між щоками перелому, 10 мм |
| `08_F_tower_x2.stl` | 2 | 27.8 × 31.0 × 2.4 | 0.82 | 340 | — | [с. 9](../drawings/parts.pdf#page=9) | Вежа F (база циліндра рукояті), лист 12 мм |
| `09_A_doubler_x2.stl` | 2 | 26.0 × 26.0 × 2.0 | 0.79 | 393 | — | [с. 10](../drawings/parts.pdf#page=10) | Накладка осі A, 10 мм |
| `10_B_fork_x2.stl` | 2 | 84.6 × 46.0 × 2.4 | 4.41 | 1836 | — | [с. 11](../drawings/parts.pdf#page=11) | Пластина вилки B (стріла–рукоять), лист 12 мм |

## Рукоять

| Файл | К-сть | Габарит XYZ, мм | Об'єм, см³ | Низ, мм² | Полиці | Ескіз | Опис |
|---|---:|---|---:|---:|---|---|---|
| `11_cheek_x2.stl` | 2 | 134.3 × 47.7 × 1.6 | 5.21 | 3258 | — | [с. 12](../drawings/parts.pdf#page=12) | Щока п'яти рукояті, лист 8 мм |
| `12_heel_rib_x1.stl` | 1 | 62.2 × 12.0 × 2.0 | 1.39 | 746 | — | — | Ребро п'яти між щоками, 10 мм |
| `13_H_clevis_x2.stl` | 2 | 22.1 × 18.5 × 2.4 | 0.66 | 277 | — | [с. 13](../drawings/parts.pdf#page=13) | Вилка H (база циліндра ковша), лист 12 мм |
| `14_H_saddle_x1.stl` | 1 | 24.0 × 12.0 × 2.0 | 0.58 | 288 | — | — | Сідло вилки H між виступами щік, 10 мм |
| `15_tip_plate_x2.stl` | 2 | 64.4 × 31.9 × 2.0 | 2.87 | 1433 | — | [с. 14](../drawings/parts.pdf#page=14) | Накладка кінця рукояті під втулки осей E і R, 10 мм |

## Важільна система

| Файл | К-сть | Габарит XYZ, мм | Об'єм, см³ | Низ, мм² | Полиці | Ескіз | Опис |
|---|---:|---|---:|---:|---|---|---|
| `16_rocker_plate_x2.stl` | 2 | 71.7 × 15.8 × 2.0 | 1.81 | 905 | — | [с. 15](../drawings/parts.pdf#page=15) | Пластина коромисла, лист 10 мм |
| `17_link_plate_x2.stl` | 2 | 54.8 × 63.3 × 2.0 | 1.88 | 941 | — | [с. 16](../drawings/parts.pdf#page=16) | Тяга ковша, лист 10 мм |

## Ківш

| Файл | К-сть | Габарит XYZ, мм | Об'єм, см³ | Низ, мм² | Полиці | Ескіз | Опис |
|---|---:|---|---:|---:|---|---|---|
| `18_bk_shell_x1.stl` | 1 | 58.3 × 52.1 × 57.6 | 6.44 | 112 | — | [с. 6](../drawings/parts.pdf#page=6) | Обичайка ковша, 5 мм — розгортка 559×288, гнути полиця/R55/спинка/R115/дно |
| `19_bk_side_L_x1.stl` | 1 | 67.0 × 52.1 × 1.2 | 2.81 | 2383 | — | [с. 17](../drawings/parts.pdf#page=17) | Боковина ковша ліва, лист 6 мм — логотип на зовнішній грані |
| `19_bk_side_R_x1.stl` | 1 | 67.0 × 52.1 × 1.2 | 2.81 | 2383 | — | [с. 17](../drawings/parts.pdf#page=17) | Боковина ковша права (дзеркальна до лівої), лист 6 мм — логотип на зовнішній грані |
| `20_bk_top_x1.stl` | 1 | 34.0 × 60.0 × 1.6 | 3.26 | 2040 | — | — | Накладка під вуха ковша, 8 мм |
| `21_bk_lip_rib_x1.stl` | 1 | 8.0 × 57.6 × 1.6 | 0.74 | 461 | — | — | Ребро губи ковша, 8 мм |
| `22_bk_ear_x2.stl` | 2 | 23.2 × 44.4 × 2.4 | 1.62 | 677 | — | [с. 18](../drawings/parts.pdf#page=18) | Вухо ковша (осі E і Q), лист 12 мм |
| `23_bk_edge_x1.stl` | 1 | 20.0 × 60.0 × 2.4 | 2.62 | 1200 | — | — | Ніж ковша 300×100×12 — ЗНОСОСТІЙКА сталь, фаска зверху 34° |
| `24_bk_tooth_x3.stl` | 3 | 22.4 × 26.1 × 8.0 | 0.84 | 105 | — | — | Зуб ковша — покупний приварний або з поковки |
| `25_bk_wear_x2.stl` | 2 | 37.1 × 9.8 × 8.0 | 0.39 | 49 | — | — | Смуга зносу на п'яті ковша, 6 мм — гнути по радіусу п'яти |

## Колона

| Файл | К-сть | Габарит XYZ, мм | Об'єм, см³ | Низ, мм² | Полиці | Ескіз | Опис |
|---|---:|---|---:|---:|---|---|---|
| `26_post_plate_x2.stl` | 2 | 50.0 × 112.0 × 2.4 | 8.86 | 3612 | 1.5% (0.5 мм) | — | Плита поворотної колони, 12 мм — осі A і C |

## Гідроциліндри

| Файл | К-сть | Габарит XYZ, мм | Об'єм, см³ | Низ, мм² | Полиці | Ескіз | Опис |
|---|---:|---|---:|---:|---|---|---|
| `27_cyl_boom_body_x1.stl` | 1 | 130.8 × 18.0 × 15.2 | 15.73 | 231 | 9.4% (11.5 мм, 0.5 мм) | — | Гільза циліндра стріли Ø63 з каналом під шток (покупний вузол) |
| `28_cyl_boom_rod_x1.stl` | 1 | 124.8 × 11.6 × 8.0 | 6.12 | 231 | 6.6% (0 мм, 1 мм) | — | Шток циліндра стріли Ø40 |
| `29_cyl_stick_body_x1.stl` | 1 | 110.3 × 14.8 × 12.0 | 9.39 | 301 | 7.1% (8.5 мм, 0 мм) | — | Гільза циліндра рукояті Ø50 з каналом під шток |
| `30_cyl_stick_rod_x1.stl` | 1 | 104.3 × 10.6 × 5.0 | 2.26 | 276 | — | — | Шток циліндра рукояті Ø25 |
| `31_cyl_bucket_body_x1.stl` | 1 | 92.3 × 14.8 × 12.0 | 7.81 | 245 | 7.2% (0 мм, 8.5 мм) | — | Гільза циліндра ковша Ø50 з каналом під шток |
| `32_cyl_bucket_rod_x1.stl` | 1 | 84.3 × 10.6 × 5.0 | 1.87 | 237 | — | — | Шток циліндра ковша Ø25 |

## Втулки й бобишки

| Файл | К-сть | Габарит XYZ, мм | Об'єм, см³ | Низ, мм² | Полиці | Ескіз | Опис |
|---|---:|---|---:|---:|---|---|---|
| `33_A_bushing_x1.stl` | 1 | 13.2 × 13.2 × 28.0 | 3.04 | 108 | — | — | Втулка-бобишка осі A, труба Ø66/30×140 |
| `34_B_bushing_x1.stl` | 1 | 13.2 × 13.2 × 15.2 | 1.65 | 108 | — | — | Втулка-бобишка осі B, Ø66/30×76 |
| `35_E_bushing_x1.stl` | 1 | 13.2 × 13.2 × 16.0 | 1.74 | 108 | — | — | Втулка-бобишка осі E, Ø66/30×80 |
| `36_R_bushing_x1.stl` | 1 | 9.0 × 9.0 × 16.0 | 0.57 | 35 | — | — | Втулка осі коромисла R, Ø45/30×80 |
| `37_G_boss_x2.stl` | 2 | 7.8 × 7.8 × 3.3 | 0.09 | 27 | — | — | Розпірна втулка осі G, Ø39/25.5×16.5 — приварити до щоки |
| `38_J_boss_x2.stl` | 2 | 8.2 × 8.2 × 5.5 | 0.18 | 32 | — | — | Бобишка осі J, Ø41/25.5×27.5 — приварити до пластини коромисла |
| `39_link_boss_x4.stl` | 4 | 10.0 × 10.0 × 5.0 | 0.29 | 58 | — | — | Бобишка тяги на осях J і Q, Ø50/25.5×25 — приварити зовні до тяги |
| `40_bk_boss_E_x2.stl` | 2 | 12.0 × 12.0 × 2.0 | 0.17 | 84 | — | — | Зовнішня бобишка вуха ковша на осі E, Ø60/30.5×10 |
| `41_bk_spacer_Q_x1.stl` | 1 | 9.0 × 9.0 × 16.4 | 0.71 | 43 | — | — | Розпірна втулка осі Q між вухами ковша, Ø45/25.5×82 |
| `42_washer_B_x2.stl` | 2 | 15.2 × 15.2 × 0.4 | 0.06 | 152 | — | — | Упорна шайба осі B, Ø76/30.5×2 |

## Пальці

| Файл | К-сть | Габарит XYZ, мм | Об'єм, см³ | Низ, мм² | Полиці | Ескіз | Опис |
|---|---:|---|---:|---:|---|---|---|
| `43_pin_A_x1.stl` | 1 | 7.2 × 7.2 × 36.9 | 0.92 | 41 | — | — | Палець осі A — стріла на колоні, Ø30×182 |
| `44_pin_C_x1.stl` | 1 | 7.2 × 7.2 × 36.9 | 0.92 | 41 | — | — | Палець осі C — база циліндра стріли в плитах колони, Ø30×182 (як палець A, НЕ як D) |
| `45_pin_B_x1.stl` | 1 | 7.2 × 7.2 × 26.1 | 0.66 | 41 | — | — | Палець осі B — стріла–рукоять, Ø30×128 |
| `46_pin_D_x1.stl` | 1 | 7.2 × 7.2 × 15.3 | 0.39 | 41 | — | — | Палець осі D — шток циліндра стріли, Ø30×74 |
| `47_pin_E_x1.stl` | 1 | 7.2 × 7.2 × 30.5 | 0.77 | 41 | — | — | Палець осі E — рукоять–ківш, Ø30×150 |
| `48_pin_F_x1.stl` | 1 | 6.2 × 6.2 × 14.7 | 0.26 | 30 | — | — | Палець осі F — база циліндра рукояті, Ø25×71 |
| `49_pin_G_x1.stl` | 1 | 6.2 × 6.2 × 19.7 | 0.34 | 30 | — | — | Палець осі G — шток циліндра рукояті, Ø25×96 |
| `50_pin_H_x1.stl` | 1 | 6.2 × 6.2 × 14.7 | 0.26 | 30 | — | — | Палець осі H — база циліндра ковша, Ø25×71 |
| `51_pin_J_x1.stl` | 1 | 6.2 × 6.2 × 40.1 | 0.68 | 30 | — | — | Палець осі J — шток циліндра ковша, Ø25×198 |
| `52_pin_Q_x1.stl` | 1 | 6.2 × 6.2 × 40.1 | 0.68 | 30 | — | — | Палець осі Q — тяга–ківш, Ø25×198 |
| `53_pin_R_x1.stl` | 1 | 7.2 × 7.2 × 20.9 | 0.53 | 41 | — | — | Палець осі R — коромисло, Ø30×102 |

## Позначення

- **Ескіз** — сторінка `parts.pdf` з контуром і розмірами деталі В МЕТАЛІ (з теки версії).
  Є тільки для пластин, труб і обичайки: смуги, круглі деталі й пальці окремих
  аркушів не мають — їхні розміри повністю описані рядком специфікації.
- **Низ** — площа, якою деталь лежить на столі. Менше ~20 мм² — обов'язковий brim.
- **Полиці** — частка площі, що друкується в повітрі майже горизонтально, і висота
  найбільших над столом. Дужки з висотою 0.5–1.5 мм означають підсічки під
  пластинами: підпора зі столу їх бере. Полиці всередині труб — це містки, не звиси
  (див. print3d-parts/README.md), підпору туди пускати НЕ можна.
- Габарити — уже в друкованих міліметрах, деталі повернуті в позу друку.

---
<sub>Ihor Ivaniuk · @IBITLAB</sub>

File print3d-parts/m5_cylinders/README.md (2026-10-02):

# Циліндри моделі 1:5 на шпильці M5 і моторедукторі N20

Робочий варіант циліндрів друкованого набору: окремі деталі поруч із «глухими» циліндрами з `parts.tsv`, не замість них. Тут лише джерела. Збирає їх `print3d-parts/make.sh` (крок «циліндри на шпильці M5»), результат лежить у [`latest/print3d/m5_cylinders/`](../../latest/print3d/m5_cylinders/): `stl/`, `img/` і [`CALC.md`](../../latest/print3d/m5_cylinders/CALC.md) з розрахунком.

Циліндри повторюють гідроциліндри моделі: **зведена довжина, хід, вушка й зовнішній Ø гільзи ті самі, що в `scad/excavator_boom.scad` (1:5)**. Рух дає шпилька M5×0.8: гайка крутиться, шпилька (шток) їде. Мотор — 12GAN20-298 на 60 об/хв, шестерні 1:1.

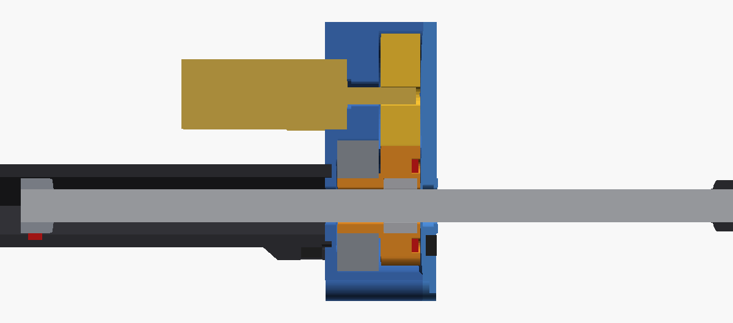
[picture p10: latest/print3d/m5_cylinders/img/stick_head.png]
розріз голови


## Як влаштовано

```
 кришка з вушком       гільза (канал-шестигранник)          голова          ніс  вушко штока
 ┌──┐┌──────┐══════════════════════════════════╗┌──────────────┐┌─┐
 │ o││ [Г]  │  ← гайка-поршень на хвості       ║│ губа│698ZZ│Ш │┤ ├─────────── o
 └──┘└──────┘══════════════════════════════════╝│     │     │ │ │└─┘  шпилька M5
   Хз                                        Хр  └──────────────┘
                                   [ N20 ]──────── шестерня мотора
```

- **Шпилька — це шток і не крутиться.** Поршень — звичайна сталева гайка M5 (7.9 під ключ, 8.97 по вершинах, 4 мм), накручена на хвіст шпильки на клей. Вона ковзає в шестигранному каналі гільзи 8.4 під ключ (зазор 0.25 на бік) і не дає шпильці провертатися: з будь-якого положення гайка впирається вершинами в грані, провернувшись не більше ніж на ~10°, а це ~0.02 мм ходу. Навантаження лягає на шість граней, а не на одне ребро, як у колишнього друкованого поршня, і різьба сталь по сталі. Вушко штока вкручується на передній кінець.
- **Гайка — у шестерні.** Два варіанти шестерні, на вибір. `*_gear`: гайка M5 закладається на паузі друку, замкнена з обох боків і не випаде. `*_gear_glue`: гніздо відкрите на передній торець, гайка вставляється після друку й садиться на клей; зірвану гайку далі 0.4 мм не пустить передня стінка голови. Шестерня завтовшки 5.7 мм і вміщає гайку до 4.8 мм (DIN 934 — 4.0, ISO 4032 — до 4.7). Маточина шестерні сидить у підшипнику 698ZZ (8×19×6).
- **Голова стоїть там, де шток виходить із корпусу.** Інакше не можна: хвіст шпильки мусить мати куди втягтися. Тому зведений циліндр ховає шпильку в гільзі, а розкритий виводить її через гайку назовні.
- **Мотор — паралельно, збоку.** Корпус N20 лежить уздовж гільзи, вал заходить у голову, на валу — шестерня 27 зубів, модуль 0.6, така сама, як шестерня гайки (1:1). Редуктор утоплено в гніздо задньої частини голови на 2.5 мм, поруч із підшипником, між гніздами — стінка 1.55 мм. Так міжосьова лишилась 16.2 мм, а вал 10 мм (Ø3.05) проходить шестерню мотора на 4.4 мм, як і з MR128. Мотор кріпиться двома гвинтами M1.6 у торець редуктора, хвіст — краплею клею до гільзи. Усі три мотори стоять ліворуч (+Y, якщо дивитись від колони на ківш): мотори й джгути на одному боці, і мотор виходить із площини механізму, де все рухається. Зіткнень з машиною немає (`make.sh collide`); датчики кінцевиків — на правому боці, навпроти мотора.
- **Упори механічні.** Зведений — поршень об дно кришки. Розкритий — поршень об губу голови. Губа тримає лише зовнішнє кільце підшипника, а поршень б'є в нерухому частину, не в шестерню, яка крутиться. Шийка вушка штока голови не торкається (зазор 1 мм).
- **Голова з двох деталей.** Задня частина (губа, гніздо підшипника, камера шестерень, гніздо редуктора) друкується заднім торцем на стіл; єдина стеля в ній — міст 10 мм над гніздом редуктора. Передня стінка з носом-напрямною несе датчики енкодера. Стягуються трьома саморізами M2, і вісь опиняється всередині трикутника кріплення: інакше шестерня гайки, що тисне на стінку, підважувала б її з боку мотора. Два саморізи стоять у перешийках між камерою шестерні гайки й камерою шестерні мотора (±43° від мотора, радіус 11.5), повністю в обрисі голови й без вушок. Третій — у вушку на 200°. Верхній передній край стінки знято фаскою 1.4 мм: на −90° стріли туди підходить вилка D.

Стек голови від заднього торця: губа 1.8 (у ній паз, куди вклеюється гільза) · 698ZZ 6.0 · 0.3 · шестерня 5.7 · 0.4 · передня стінка 2.0 = 16.2 мм. Підшипник на 2.5 мм товщий за колишній MR128, шестерня під гайку 4.8 — на 0.7 мм, а зведена довжина задана моделлю. Тому поршень став коротшим (6 → 4 мм, тепер це сталева гайка), а зазор між вушком штока й носом у зведеному — меншим (1 → 0.5 мм). Носа-напрямної у стріли й рукояті лишилось 0.1 мм, у ковша 2.1 мм. Шпильку ведуть гайка й отвір передньої стінки.

**Як 698ZZ стає на місце.** Гніздо й камера шестерні перед ним — одним діаметром 19.4 мм, на передньому торці заходка 0.5 мм. Підшипник вільно проходить крізь камеру; у першій пробі камера була Ø18.4 і не пускала його до гнізда. Тримають його 8 ребер з вершинами на Ø19 і скосом угорі. Ребра надруковуються трохи товщими й зминаються, тож кільце запресовується пальцем, а не молотком. Сів вільно — крапля клею по зовнішньому кільцю. Щільніше чи вільніше — `PRESS` (вершини ребер) у `m5_cyl.scad`.

## Зворотний зв'язок

**Енкодер — оберти й напрямок.** У передньому торці шестерні гайки два магніти Ø2×1 під 180°, повернуті назустріч різними полюсами (N і S). Навпроти них у передній стінці стоять два латчі Холла SS41F під 90° один до одного. Латч вмикається від N і вимикається від S, тож кожен дає меандр 50/50, а два разом дають квадратуру: 4 фронти на оберт гайки = **0.2 мм ходу** на фронт. Напрямок видно з того, який сигнал випереджає. Магніти стоять навпроти граней гайки, де між гайкою й западиною зубів найбільше пластику.

**Кінцевики — магніт у поршні.** Про «паличку до кнопки» подумав, і ось чому зробив інакше:

- У цій схемі **обидва крайні положення й так видно біля голови**. Розкритий — поршень підходить упритул до голови. Зведений — вушко штока підходить до носа. Паличка через увесь циліндр не потрібна.
- **Кнопки тут ламаються.** Тактова кнопка має хід 0.25 мм і жодного перебігу. N20 на 298:1 тисне на упор сотнями ньютонів (`CALC.md`), і кнопку в ланцюжку упору розчавить. Мікроперемикач із важелем (12.8×5.8 мм) має перебіг, але завбільшки з половину гільзи.
- **Замість кнопок — датчики Холла, без жодної рухомої деталі.** На грані гайки-поршня магніт Ø2×1, такий самий, як в енкодері; на сталі він тримається сам, клей — для певності. Датчик «розкритий» стоїть у приливі гільзи одразу за головою (той «горбик» на гільзі — це він), датчик «зведений» — у приливі задньої кришки. Обидва дивляться крізь стінку гільзи на грань гайки з магнітом. Зсередини вздовж цієї грані йде паз на всю довжину гільзи, у якому магніт їде весь хід (і гайку з магнітом можна прогнати крізь ще не вклеєну гільзу для примірки); стінка між пазом і датчиком — 0.75 мм у рукояті й ковша, 2.35 мм у стріли. Це лінійні SS49E: їхній вихід відхиляється від середньої напруги вгору чи вниз залежно від полюса, тож полюс магніту не важить, а точку спрацювання задає прошивка. На упорі поле біля датчика 12–31 мТл, що при живленні 3.3 В дає відхилення 80–360 мВ. Поріг «половина відхилення на упорі» спрацьовує, коли до упору лишається ~1.5–2 мм. Дроти «зведеного» йдуть до голови канавкою вздовж гільзи (на 60° від осі датчиків: під самими датчиками зсередини паз магніту), тож з циліндра виходить **один джгут біля голови**, як ти й хотів.

**Усі датчики й магніти вставляються після друку** — як саме й куди дивиться маркування, показано на `SENSORS.svg` (поруч із `CALC.md` у зібраному наборі). Гнізда відкриті назовні й мають запас 0.2 мм по ширині й висоті корпусу. Гнізда SS49E відкриті радіально, з боку приливів, ніжки виходять прорізом 3.2 мм: у датчика «зведений» — до краю стакана кришки, у датчика «розкритий» — до кришки, крізь увесь прилив (з боку голови від корпусу до її торця лише 0.35 мм, ніжки там не загнути). Гнізда SS41F відкриті на передній торець передньої стінки, ніжки йдуть назовні канавками 3.2×1.0. Магніти енкодера вставляються в торець шестерні, магніт кінцевиків — на грань гайки-поршня. На паузі друку закладається лише гайка M5 у шестерню `*_gear`; з `*_gear_glue` пауз немає зовсім.

Якщо все ж потрібна механіка, на цю ж схему лягає варіант із палички. Сталевий дріт Ø1 лежить у пазу гільзи. Поршень у крайніх положеннях зсуває його на ~1 мм. Загнутий кінець дроту виходить біля голови між двома мікроперемикачами з важелями. Упор мусить бути окремим (поршень об губу), щоб сила не йшла через дріт.

## Покупне на один циліндр

| Що | К-сть | Примітка |
|---|---:|---|
| Шпилька M5×0.8 (DIN 976), довжина — у `CALC.md` | 1 | сталь, торці зачистити; закладено Ø4.85 (виміряна) |
| Гайка M5 сталева (7.9 під ключ, 4 мм) | 1 | поршень, на клей на хвіст шпильки; розміри — `PISTON` у `m5_cyl.scad` |
| Гайка M5 ходова, латунна (S8, висота до 4.8) | 1 | на паузі в `*_gear` (висоту гайки — у `M5_NUT_H`, щоб не було люфту) або на клей у `*_gear_glue` |
| Підшипник 698ZZ (8×19×6) | 1 | у натяг на маточину й у гніздо |
| Моторедуктор 12GAN20-298, 60 об/хв, 12 В | 1 | вал Ø3.05 (виміряний) з лиською, 10 мм |
| Гвинт M1.6×5 | 2 | мотор до голови |
| Саморіз M2×8 | 3 | передня стінка до голови: 2 у перешийках, 1 у вушку |
| Магніт N52 Ø2×1 | 3 | 2 — енкодер, полюси назустріч (N і S); 1 — поршень, кінцевики, полюс будь-який |
| Латч Холла SS41F (плаский TO-92, 4.1×3.0×1.6) | 2 | енкодер; живлення 4.5–24 В — від 5 В |
| Лінійний датчик Холла SS49E (плаский TO-92, 4.1×3.0×1.6) | 2 | кінцевики; живлення 3.3 В, вихід — на АЦП. Цифрові A3144 чи SS451A з магнітом Ø2×1 біля кришки стріли не спрацюють напевно |
| Контролер ESP32-C3 SuperMini | 1 | свій на кожен циліндр |
| Драйвер мотора з обмеженням струму (DRV8871) | 1 | див. «Підключення й керування» |
| Резистор 10 кОм | 2 | підтягування виходів SS41F до 3.3 В |

Усього на три циліндри: 3 мотори, 3 підшипники, 9 магнітів Ø2×1, 6 SS41F, 6 SS49E, 3 контролери, 3 драйвери.

## Друк

| Деталь | Як класти | Примітка |
|---|---|---|
| Гільза `*_tube` | стоячи, заднім торцем на стіл | шестигранний канал і паз магніту — вертикальні, без підпор |
| Голова, задня `*_head_rear` | заднім торцем (з пазом під гільзу) на стіл | міст 10 мм над гніздом редуктора |
| Передня стінка `*_head_front` | стиком донизу, носом догори | кишені датчиків догори |
| Шестерня гайки `*_gear` | переднім торцем (магніти) на стіл | **пауза** перед шаром 5.3 мм (стеля гнізда гайки 4.8), вкласти гайку |
| або `*_gear_glue` | переднім торцем (магніти й гніздо гайки) на стіл | без пауз; гайка — після друку, на клей |
| Шестерня мотора `*_pinion` | плазом | отвір під вал з лиською, у натяг |
| Кришка `*_cap` | стаканом донизу | дно — міст над стаканом |
| Вушко штока `*_eye` | шийкою донизу | отвір 4.63 під шпильку |

Шестерні модуля 0.6 — межа для сопла 0.4: друкувати шаром 0.1 і повільно. Перед усім набором надрукуй пробу: голову (підшипник у ребра, `PRESS`), шестерню мотора на вал (`SHAFT_FIT`), вушко на шпильку (`HOLE_SHRINK`) і гайку-поршень у гільзу (`PISTON_FIT`).

Посадки після першої проби (усі — у групі «Допуски друку» `m5_cyl.scad`):

| Що | Було | Стало |
|---|---|---|
| 698ZZ у голові | гніздо Ø19, камера Ø18.4 — не проходив | камера й гніздо Ø19.4, 8 ребер до Ø19 |
| маточина в підшипнику | Ø8.0 | Ø7.9 (`HUB_FIT`) |
| шестерня мотора на вал Ø3.05 | отвір +0.05 — не наліз | +0.35 (`SHAFT_FIT`) |
| отвір під шпильку у вушку | 4.43 — замалий | 4.63 (`HOLE_SHRINK` 0.3) |
| поршень | друкований, у гільзі 0.15 на бік — затуго | сталева гайка в шестигранному каналі 8.4 під ключ (`PISTON_FIT` 0.25) |
| гнізда магнітів Ø2×1 | Ø2.1, глибина 1.05–1.1 | Ø2.25, глибина 1.3 (`MAG_CLR`) |

**Отвір під шпильку** у вушку — `TAP_D` = 4.63. Це Ø4.85 шпильки мінус ~60 % профілю різьби M5×0.8, плюс 0.3 мм (`HOLE_SHRINK`) на те, що надрукований отвір виходить меншим. Шпилька має нарізати різьбу від руки, без розсвердлювання. Якщо йде туго чи вільно — підправ `STUD_D` чи `TAP_D` у `m5_cyl.scad`.

## Складання

1. Гайку — у шестерню: у `*_gear` на паузі друку, у `*_gear_glue` після друку на клей (клей — на грані, не в різьбу; шпилькою прогнати, поки клей не схопився). У передній торець вклеїти 2 магніти Ø2×1 різними полюсами назовні. Полюс перевір іншим магнітом: один має притягуватися, другий відштовхуватися.
2. 698ZZ вставити в задню частину голови з переднього торця, крізь камеру, і втиснути в ребра до губи. Маточину шестерні вставити в підшипник.
3. Мотор: редуктор вставити в гніздо голови, закріпити двома M1.6, шестерню — на вал з боку камери. Перевірити, що пара крутиться від руки без заїдань.
4. Вклеїти датчики енкодера в передню стінку маркуванням до шестерні (`SENSORS.svg`), вивести дроти канавками. Стягнути голову трьома M2.
5. Гільзу вклеїти в паз голови. Вона стає лише одним боком: острівець у пазу голови — шестигранник із виступом, що заходить у паз магніту гільзи (паз — з боку приливу датчиків).
6. Сталеву гайку-поршень накрутити на хвіст шпильки врівень з торцем, посадити на клей. На її грань — магніт Ø2×1. Шпильку вставити в гільзу **із заднього кінця**, гайкою в шестигранник і магнітом у паз (паз — з боку приливу датчиків і мітки на торці), і загнати в ходову гайку, крутячи мотор. Гайка-поршень крізь ходову гайку не пройде, тому інакше шпильку не вставити.
7. Датчики кінцевиків вклеїти маркуванням до гільзи (`SENSORS.svg`), ніжками в проріз: «зведений» — у прилив кришки, ніжками до краю стакана; «розкритий» — у прилив гільзи, ніжками до кришки. До ніжок «розкритого» припаяти дроти в кінці прорізу й повести їх уперед, поверх приливу, до вирізу голови. Кришку вклеїти на гільзу. Кришка теж стає лише одним боком: ребро на стінці стакана заходить у канавку дротів гільзи, і прилив датчика «зведений» опиняється над пазом магніту. Дроти «зведеного» від краю стакана покласти в ту саму канавку: вона йде вздовж гільзи на 60° від осі датчиків, збоку від приливу «розкритий». Біля голови загнути всі дроти назовні, у виріз голови.
8. Вушко штока вкрутити на шпильку, що вийшла з носа, повернути паралельно вушку кришки (пальці мають бути паралельні) і посадити на клей.

## Підключення й керування

Кожен циліндр має свій контролер ESP32-C3 SuperMini. Уся схема одного циліндра — `WIRING.svg` поруч із `CALC.md` у зібраному наборі (`latest/print3d/m5_cylinders/`). З циліндра до контролера йде 9 дротів: 5 В (для SS41F), 3.3 В (для SS49E), GND, ENC_A, ENC_B, LIM_EXT, LIM_RET, M+ і M−.

| Сигнал | Вивід SuperMini | Примітка |
|---|---|---|
| ENC_A, ENC_B | GPIO5, GPIO6 | відкритий колектор SS41F: 10 кОм до 3.3 В. Лічильника імпульсів у C3 немає, тож фронти рахує переривання на обидва фронти обох входів |
| LIM_EXT, LIM_RET | GPIO3, GPIO4 (ADC1) | SS49E від 3.3 В; АЦП з ослабленням 12 дБ міряє до ~2.5 В, а датчик дає 1.5–2.2 В |
| IN1, IN2 драйвера | GPIO7, GPIO10 | ШІМ (LEDC) |
| не займати | GPIO2, GPIO8, GPIO9 | strapping-виводи; на GPIO8 — світлодіод плати, на GPIO9 — кнопка BOOT |

Живлення: 12 В іде на драйвер, понижувач 12→5 В — на вивід 5V плати (з цієї ж лінії живляться SS41F). 3.3 В дає стабілізатор плати, від нього живляться SS49E. Якщо на твоїй платі між USB і виводом 5V немає діода, не під'єднуй USB, поки плата живиться ззовні.

Мотор підключається через драйвер з обмеженням струму, що тримає 12 В, наприклад DRV8871. Поріг струму в ньому задає резистор ILIM, номінал бери з даташиту на ≈ 0.2 А. DRV8833 теж обмежує струм (I = 0.2 В / R_SENSE), але розрахований лише до 10.8 В. З ним мотори треба живити від ~9 В, і 60 об/хв стануть ~45.

- **Обмеження струму обов'язкове.** 298:1 на 12 В тисне на шпильку сотнями ньютонів, а друковані упори розраховані на десятки.
- **Калібрування кінцевиків.** Нуль SS49E в різних екземплярів розкиданий (1.5–1.8 В при 3.3 В), тож кожен датчик треба заміряти один раз. Спершу, коли поршень посередині ходу, записати в NVS напругу V₀ обох датчиків. Потім підвести поршень до кожного упору й записати відхилення ΔV. Кінцевик спрацював, коли |V − V₀| > ΔV / 2. АЦП C3 шумить на ~10 мВ, тож кожен замір — середнє з 8–16 вимірів.
- **Нуль.** Після ввімкнення кожен циліндр втягується до спрацювання LIM_RET. Там лічильник енкодера = 0, далі позиція = лічильник × 0.2 мм. Стан SS41F одразу після ввімкнення не визначений, але лічильник бере лише фронти, тож це не заважає.
- **Межі.** Програмні межі за лічильником (0.5 мм від кожного датчика). Датчики — друга лінія захисту, механічний упор — третя, і в нормі до нього не доходить.
- **Заїдання.** Мотор під напругою, а фронтів енкодера немає понад 0.5 с — стоп. Це ловить і упор, і перекіс.

## Розрахунок

[`CALC.md`](../../latest/print3d/m5_cylinders/CALC.md) пише `calc.py` щоразу, коли збирається набір. Там:
- довжини кожного циліндра й довжина шпильки;
- маса з самих STL;
- сила ваги на кожному циліндрі за всіма позами (з `print3d-parts/model_drive.py`);
- час ходу вибраного мотора порожнім і з повним ковшем піску;
- що дали б інші N20.

Коротко: 12GAN20-298 на 60 об/хв з шестернями 1:1 проходить хід за 75–127 с, у 25–31 раза повільніше за машину. Ківш піску мотор тягне, беручи кілька відсотків моменту.

## Відкриті питання

- **Швидкість.** 60 об/хв, 1:1 — це 0.8 мм/с, у 25–31 раза повільніше за машину: стріла проходить хід за ~2 хв. Зате тягне повний ківш піску з запасом у десятки разів. Якщо захочеться швидше за тієї самої голови, 12GAN20-20 (1000 об/хв) дає лише у ×2 повільніше за машину без піску. Друковані деталі ті самі: корпус N20 однаковий, змінюється лише шестерня мотора.
- **Зв'язок між контролерами.** Три SuperMini треба якось узгоджувати: через ESP-NOW чи Wi-Fi (вбудовані) або дротом (UART на GPIO20/21). Ще не вирішено. У частини плат SuperMini слабка антена: якщо зв'язок рветься, допомагає знизити потужність передавача.
- **Гнізда датчиків — із запасом `HALL_FIT` = 0.2 мм** до `HALL` = 4.1×3.1×1.6 (корпус SS41F і SS49E — 4.1×3.0×1.6). Якщо датчик усе ж не лізе або бовтається, змінити `HALL_FIT`.
- **Розміри N20 звірити з тим, що приїде.** Довжина редуктора 298:1 (закладено 9 мм), вал 10 мм, отвори M1.6 через 9 мм, бобишка редуктора Ø4. Від довжини вала залежить, наскільки утоплено редуктор (`X_MF`).
- **Голова ширша за гільзу.** Ø≈21.4 мм проти 12–15 мм у гільзи, плюс мотор збоку. Менше не вийде: шестерня гайки має вмістити гайку S8 і два магніти, а гніздо — 698ZZ (Ø19).
- **Шток стріли тонший, ніж у моделі** (M5 проти Ø8 у масштабі): шпилька і є штоком.
- **Сталь важить.** Три шпильки — ~50 г. Разом із моторами це вже враховано в силах (розрахунок бере маси з цих STL).

## Файли

| Файл | Що |
|---|---|
| `m5_cyl.scad` | модель: збірка, розрізи, кожна деталь (`-D 'cyl="stick"' -D 'pp="head_rear"'`). Сталі на початку — вибір мотора, шестерень, кута мотора, розміри гільзи. Група «Що показати» в Customizer — галочки деталей збірки й розрізу, щоб зазирнути всередину |
| `calc.py` | довжини, маса, сили, час ходу → `CALC.md`; читає сталі з `m5_cyl.scad` |
| `wiring.py` | схема підключення одного циліндра → `WIRING.svg`; виводи — ті самі, що в таблиці «Підключення й керування» (змінив одне — зміни й друге) |
| `sensors.py` | як ставити SS41F і SS49E → `SENSORS.svg`: де гнізда, куди маркування, куди ніжки, де який вивід з боку вставляння; кути — з `m5_cyl.scad` |
| `make.sh` | перетини власних деталей, зіткнення з машиною, STL і друкованість, рендери, `CALC.md`, `WIRING.svg`, `SENSORS.svg` |

`print3d-parts/m5_cylinders/make.sh` сам складає все в `build/m5_cylinders/`, щоб було видно результат до збирання набору. У `latest/` це потрапляє лише через `print3d-parts/make.sh`. Окремі кроки: `make.sh pairs collide`. Інші кути мотора: `PHIS="0 90 -90 180" ALL=1 make.sh collide`.

Модель машини підключається як бібліотека й не змінюється. Довжини, хід, вушка й зовнішній Ø гільзи — з неї, тож зміниться циліндр у моделі — зміняться й ці.

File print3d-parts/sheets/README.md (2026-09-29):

# Аркуші розкладки 1:1 — сортування й склеювання набору

Купа надрукованих деталей, у якій втулки, пальці й шайби майже не відрізнити один
від одного, розбирається на папері. [`SHEETS.pdf`](../../latest/print3d/sheets/SHEETS.pdf) — шість аркушів A4, по одному на
кожен вузол, що склеюється, і окремий для пальців та шайб, якими вузли з'єднуються:

| Аркуш | Що на ньому | Файлів / штук |
|---|---|---:|
| 1 | Стріла | 10 / 15 |
| 2 | Рукоять | 10 / 14 |
| 3 | Ківш | 10 / 16 |
| 4 | Коромисло і тяга | 4 / 10 |
| 5 | Колона і гідроциліндри | 7 / 8 |
| 6 | Пальці й шайби — з'єднання вузлів, не клеїти | 12 / 13 |
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

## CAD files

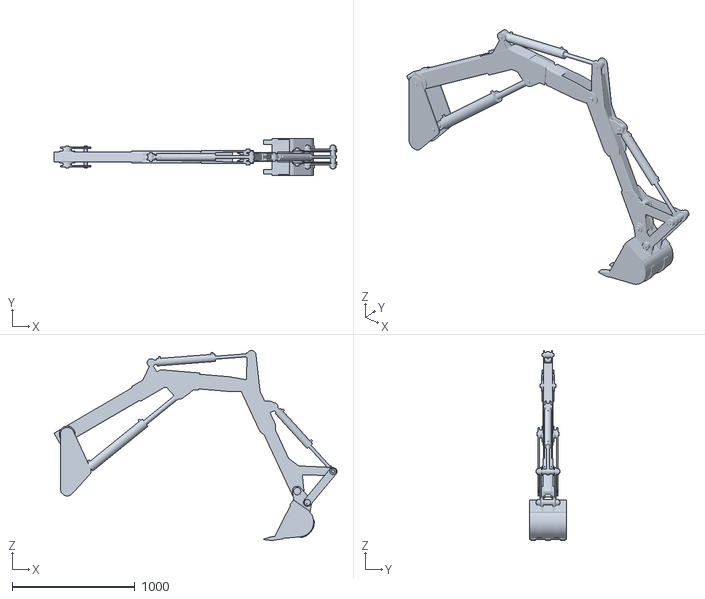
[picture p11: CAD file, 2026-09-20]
latest/stl/assembly.stl
2309.6 x 300.0 x 1551.1

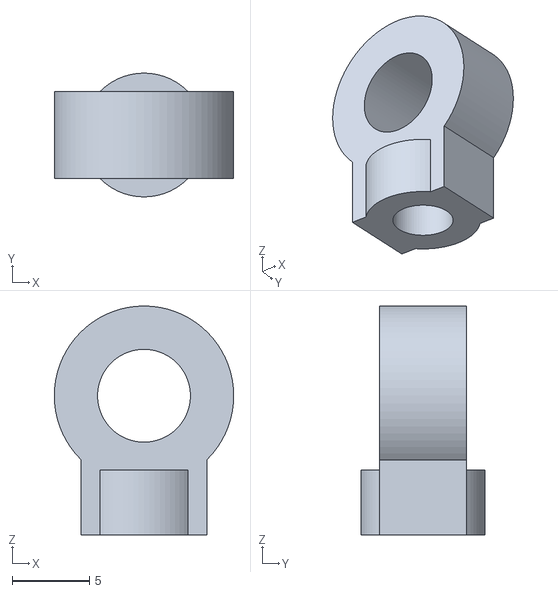
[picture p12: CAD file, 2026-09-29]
latest/print3d-history/V006.1-2026-09-29-1842/m5_cylinders/stl/boom_eye_x1.stl
11.6 x 8.00 x 14.8

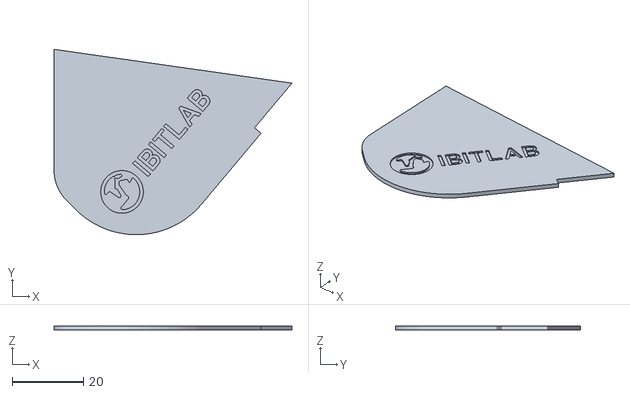
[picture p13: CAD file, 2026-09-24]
latest/print3d-history/V006.1-2026-09-29-1842/stl/1_body_yellow_0.20mm_no-supports/19_bk_side_L_x1.stl
67.0 x 52.1 x 1.20

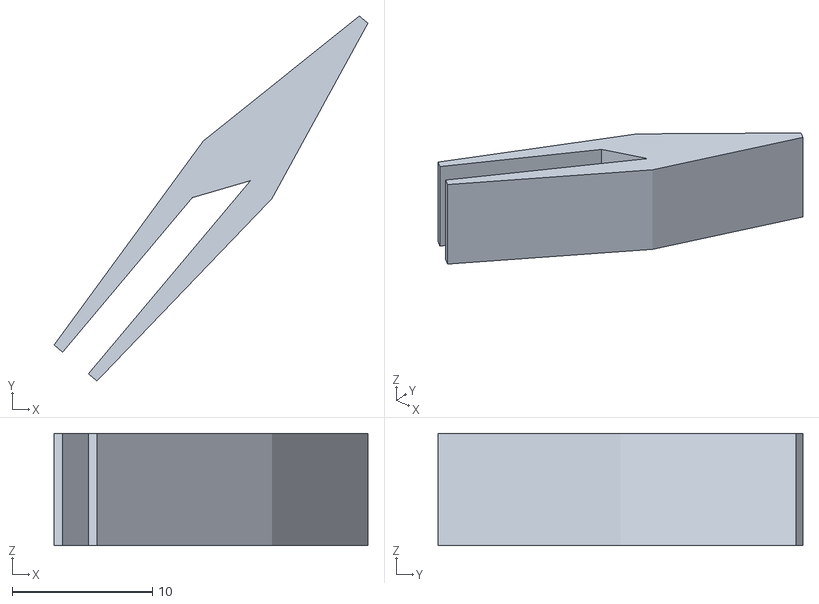
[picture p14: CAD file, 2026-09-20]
latest/print3d-history/V006.1-2026-09-29-1842/stl/2_wear_dark_0.20mm_brim/24_bk_tooth_x3.stl
22.4 x 26.1 x 8.00

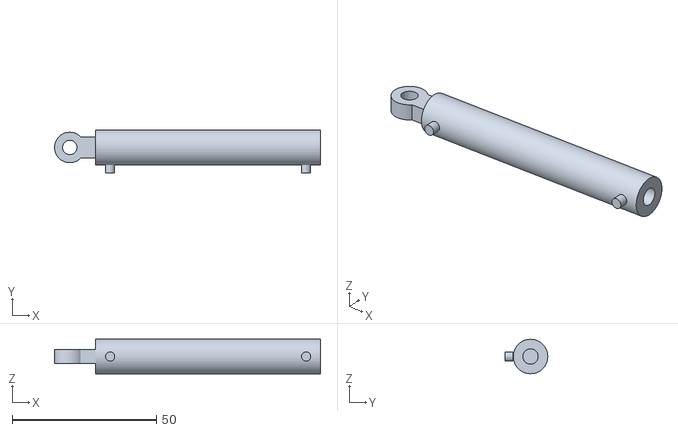
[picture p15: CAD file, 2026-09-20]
latest/print3d-history/V006.1-2026-09-29-1842/stl/3_cylinders_grey_0.20mm_supports-from-bed/31_cyl_bucket_body_x1.stl
92.3 x 14.8 x 12.0

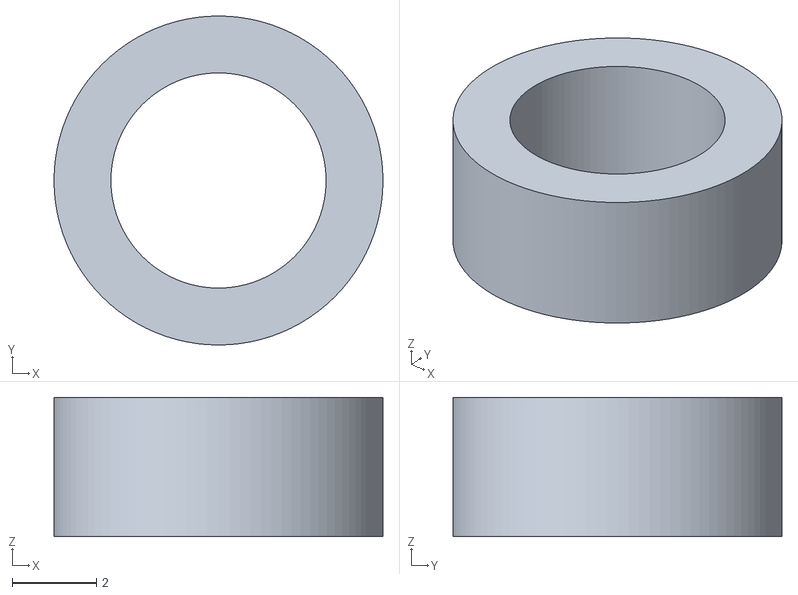
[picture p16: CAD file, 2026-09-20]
latest/print3d-history/V006.1-2026-09-29-1842/stl/4_bushings-bosses_silver_0.12mm_brim/37_G_boss_x2.stl
7.80 x 7.80 x 3.30

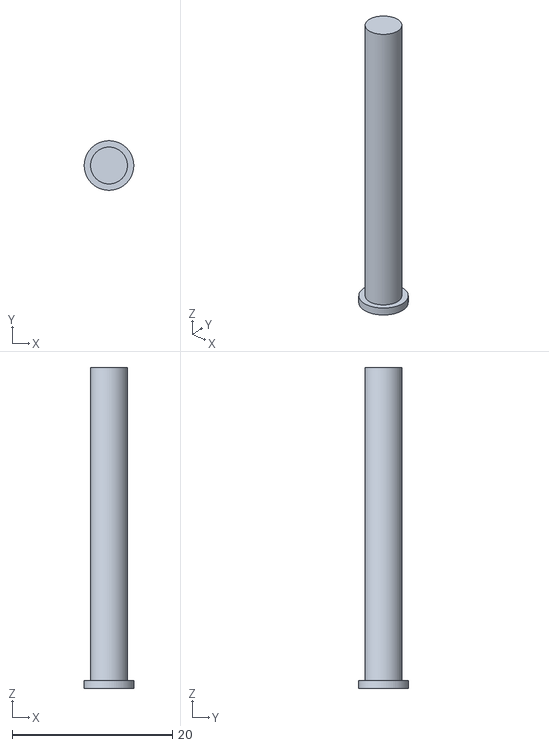
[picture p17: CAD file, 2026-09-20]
latest/print3d-history/V006.1-2026-09-29-1842/stl/5_pins_silver_0.12mm_brim/52_pin_Q_x1.stl
6.20 x 6.20 x 40.1

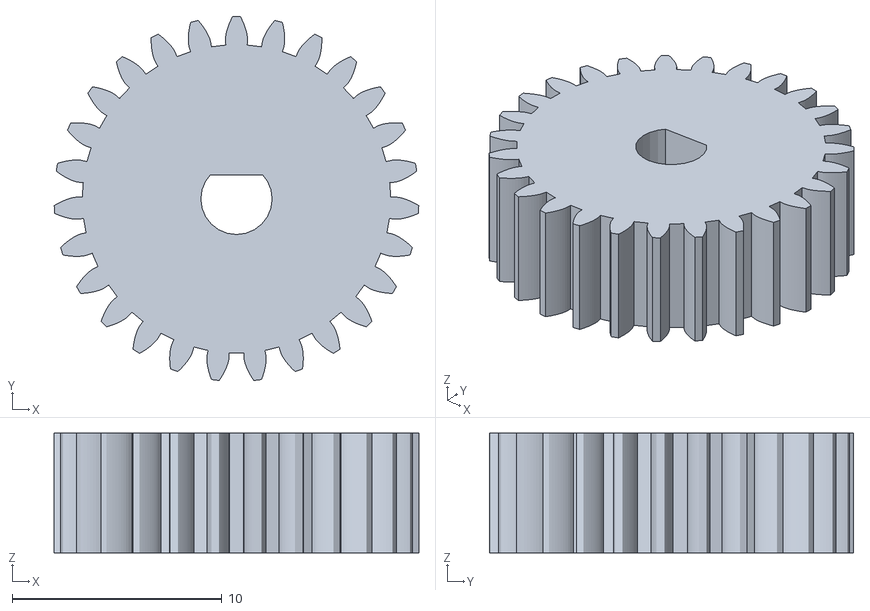
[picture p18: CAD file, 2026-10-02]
latest/print3d/m5_cylinders/stl/boom_pinion_x1.stl
17.4 x 17.4 x 5.70

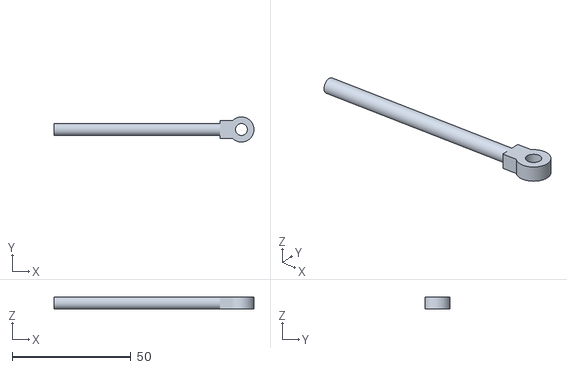
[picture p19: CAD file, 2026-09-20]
latest/print3d/stl/3_cylinders_grey_0.20mm_supports-from-bed/32_cyl_bucket_rod_x1.stl
84.3 x 10.6 x 5.00

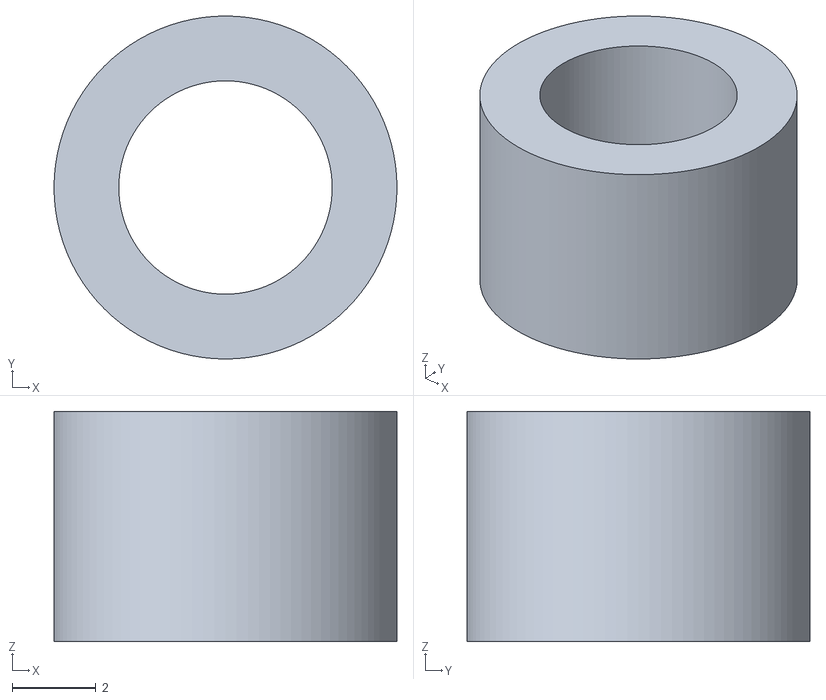
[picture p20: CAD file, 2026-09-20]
latest/print3d/stl/4_bushings-bosses_silver_0.12mm_brim/38_J_boss_x2.stl
8.20 x 8.20 x 5.50

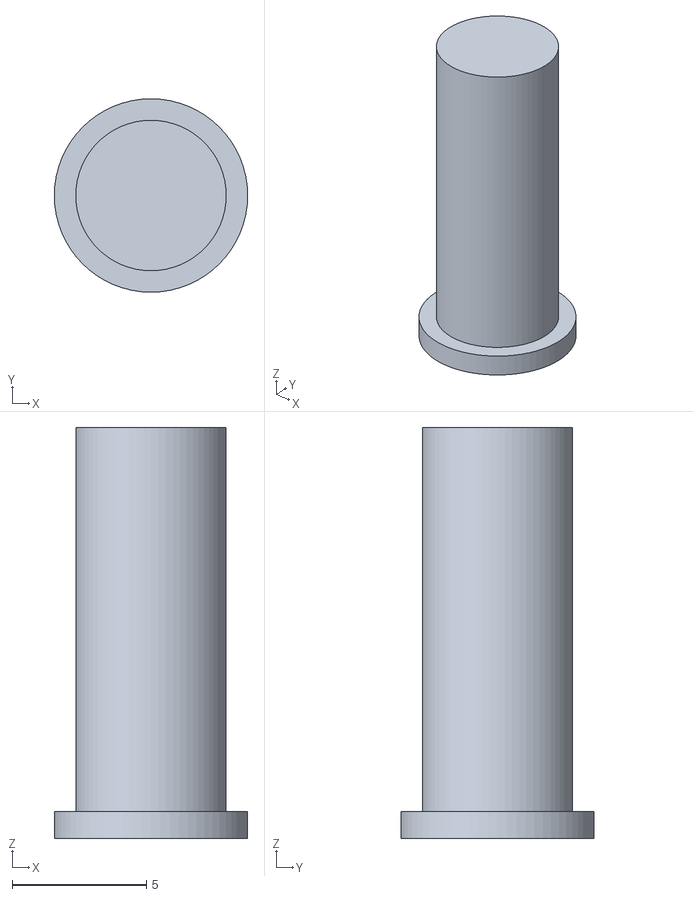
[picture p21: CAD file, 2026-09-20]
latest/print3d/stl/5_pins_silver_0.12mm_brim/46_pin_D_x1.stl
7.20 x 7.20 x 15.3

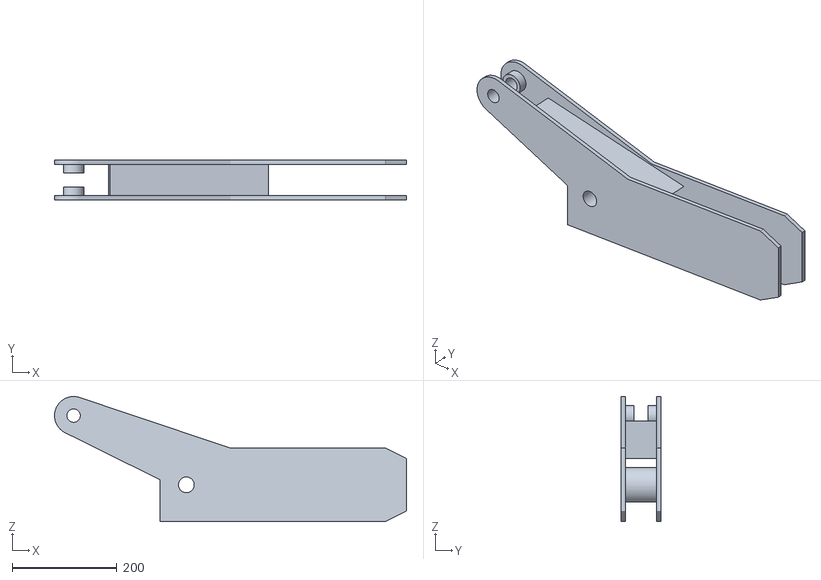
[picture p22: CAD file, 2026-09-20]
latest/stl/stick_cheeks.stl
671.5 x 76.0 x 238.5

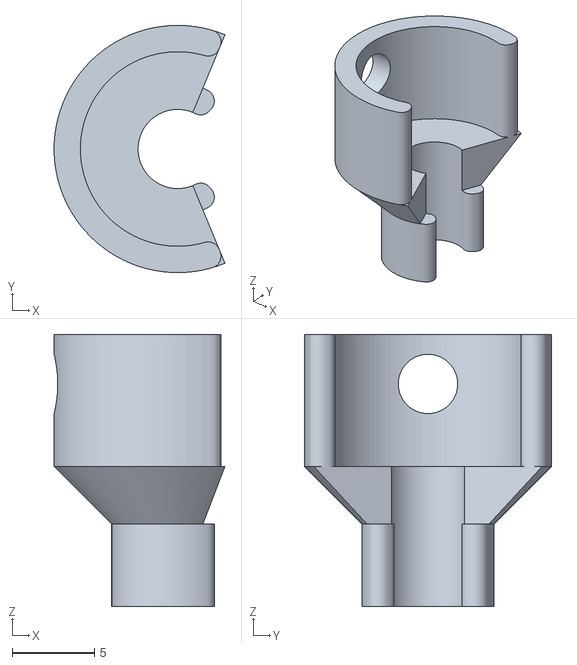
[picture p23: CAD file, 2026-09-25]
print3d-parts/stand/stl/clip_stick_bucket.stl
10.4 x 15.0 x 16.5

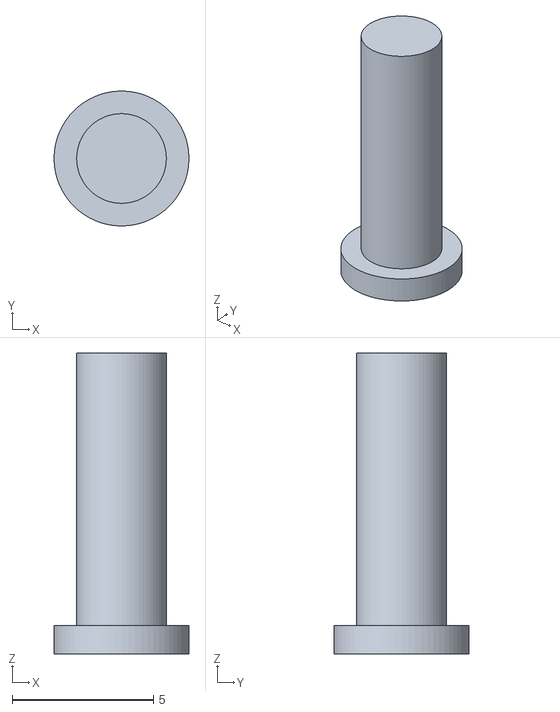
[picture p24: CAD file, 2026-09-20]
print3d/stl/22_pin_F_x1.stl
4.77 x 4.77 x 10.6

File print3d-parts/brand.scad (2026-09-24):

// =============================================================================
//  Бренд на друкованих деталях: знак у колі (+ слово) як виїмка 0.4 мм.
//
//  Місця, розміри й кути — НЕ тут, а в моделі (scad/excavator_boom.scad, розділ «ЛОГОТИП»,
//  таблиця brand_marks): звідти ж їх показують 3D-сторінки, рендери й аркуші розкладки,
//  тож надрукований знак стоїть рівно там, де його видно на сторінці. Полігони —
//  scad/brand/ (знак Ø18 і Ø12 у друкованих мм; штрихи й стінки між виїмками не тонші
//  за 0.8 мм — дві лінії сопла).
//
//  Виїмка вирізається в СИСТЕМІ ДЕТАЛІ, до укладання на стіл (lay() потім повертає все
//  разом), тому друкованих координат тут немає. Орієнтацію на столі див. parts.scad:
//  знак на трубах і плиті колони — на обох гранях (одна з них друкується на столі),
//  на боковинах ковша — на верхній, зовнішній.
//
//  Чому саме такі місця (числа — друковані мм, по STL набору):
//    - труба стріли, сегмент 1: між накладкою осі A (x ≤ 13) і щокою перелому (x ≥ 130) —
//      знак Ø18 зі словом (композиція 61 мм, x ≈ 19–81);
//    - труба рукояті: між щокою п'яти (x ≤ 84) і накладкою кінця (x ≥ 135.6) — знак Ø12
//      зі словом (композиція 42 мм; грань 20 мм завширшки, Ø18 не лишає полів, а Ø14 зі
//      словом упирається в накладки);
//    - плита колони: найширше місце профілю між отворами A і C (найбільше вільне коло Ø38
//      з центром (10.2, 46.1)) — знак Ø18;
//    - боковини ковша: знак Ø12 зі словом (Ø18 зі словом не влазить під жодним кутом),
//      центр — де до кромок найдалі (3.3 мм);
//    - сегмент 2 стріли — без бренду: між щокою перелому (до x = 60) і пластиною вилки B
//      (від x = 64) на бічній грані місця немає.
// =============================================================================
BRAND_DEPTH = 0.4;     // 2 шари по 0.2: читається тінню; стеля труби 1.0 лишає 0.6

// Деталь (children) без виїмок знаків key: глибина — BRAND_DEPTH друкованих мм,
// зріз виходить на 1 мм над поверхнею, щоб не лишилось плівки на площині грані.
module branded(key, side = 0) {
    difference() {
        children();
        brand_body(key, P(BRAND_DEPTH), P(1), side);
    }
}

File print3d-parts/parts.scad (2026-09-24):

// =============================================================================
//  Міні-екскаватор: КОЖЕН компонент окремо — так, як його ріжуть з металу
//  перед зварюванням. Друкується й склеюється як конструктор.
//
//  Труби, пластини, накладки, сідла, ребра, втулки, пальці — кожне окремо.
//
//  Модель НЕ змінюється: цей файл підключає scad/excavator_boom.scad як бібліотеку
//  (part="none") і дістає компоненти її ж механізмом $sel/$one.
//
//  Запуск завжди через make.sh:
//      openscad -o x.stl -D 'part="none"' -D 'pp="gusset"' -D 'own="boom"' parts.scad
// =============================================================================
include <../scad/excavator_boom.scad>

// Невдалий include НЕ помилка: всі модулі стають порожні, STL виходить валідним
// і порожнім, і жодна числова перевірка цього не бачить.
assert(!is_undef(boom_tube_h) && !is_undef(bush_od_main), "scad/excavator_boom.scad не підключився");

/* [Друк] */
// Масштаб 1:SC. 5 — найбільший цілий, за якого найдовша труба (рукоять, 1050 мм)
// влазить у 250 мм: 210 мм. 1:4 дало б 262.5 мм.
SC = 5;
NOZZLE = 0.4;
// Діаметральний зазор палець↔отвір, ДРУКОВАНІ мм — знімається з пальця,
// щоб не чіпати жодного отвору в моделі
FIT_PIN = 0.40;
// Шток у гільзі циліндра, друковані мм — циліндр має лишатися рухомим
FIT_SLIDE = 0.35;
// Голівка пальця, друковані мм
PIN_HEAD_D = 1.6;
PIN_HEAD_H = 1.0;

/* [Hidden] */
pp = "none";     // ключ компонента
own = "";        // вузол-власник; порожньо = компонент будується тут
ori = "y";       // яка вісь МОДЕЛІ дивиться вгору на столі: x, y, z (raw = без повороту, для обміру)
pre = 0;         // попередній поворот навколо Y моделі, ° — для деталей, нахилених у вузлі
eps = 0.01;
function P(x) = x * SC;          // друковані мм → мм моделі

// Бренд на деталях — після SC: глибина виїмки задана в друкованих мм і переводиться через P().
// Місця знаків — у моделі (brand_marks), тут лише виїмка.
include <brand.scad>
assert(!is_undef(BRAND_DEPTH) && !is_undef(brand_marks), "print3d-parts/brand.scad або розділ «ЛОГОТИП» моделі не підключився");

// Орієнтація на столі: деталь кладеться найменшим розміром догори.
//
// Єдиного правила «Y догори» НЕ досить, хоча всі осі шарнірів паралельні Y.
// Пластини вузлів справді мають товщину вздовж Y (`plate_xz(pts, t, y0)`), а от смуги
// зі списку BOM_STRIPS задані тим самим модулем, але з t = ШИРИНА деталі: у сідла H
// «товщина» 60 мм — це його ширина, а справжні 10 мм лежать у профілі. З «Y догори»
// така смуга стає на ребро (bk_top виходив 1.6 × 34 × 60 — лезо, яке впаде зі столу).
// Тому вісь задається на деталь, у parts.tsv, і звірена обміром кожної з них.
// Частина деталей до того ж стоїть у вузлі під кутом: ніж ковша, сідло D, ребро п'яти,
// накладка перелому, зуб. Їх жодна з трьох осей не кладе плазом — ніж виходив баштою
// 60 мм заввишки на основі 15×15. Усі вони призматичні вздовж Y (складова Y найбільшої
// нормалі ≈ 0), тому поворот навколо Y кладе їхню найбільшу грань на стіл. Кут `pre`
// не підібраний на око: він порахований із нормалі цієї грані (див. README).
// Бренд (brand.scad → branded()) вирізається ДО укладання, у системі самої деталі — тими
// самими місцями з моделі, що показують 3D-сторінки; lay() лише повертає і масштабує.
module lay() {
    scale(1/SC)
        if      (ori == "y") rotate([90, 0, 0]) rotate([0, pre, 0]) children();   // +Y моделі → +Z столу
        else if (ori == "x") rotate([0, -90, 0]) rotate([0, pre, 0]) children();  // +X моделі → +Z столу
        else rotate([0, pre, 0]) children();                                       // z або raw: як у моделі
}

// -----------------------------------------------------------------------------
//  Компоненти, яких у моделі немає окремими модулями
// -----------------------------------------------------------------------------
// Палець. Увесь зазор з'єднання — тут, тому жоден отвір у вузлах не переробляється.
// Палець будується вздовж +Z і друкується стоячи (ori = "z"): так його діаметр
// виходить круглим, а голівка дає і зчеплення зі столом, і упор у з'єднанні.
module make_pin(d, len) {
    dp = d - P(FIT_PIN);
    assert(dp > 0, "палець тонший за зазор");
    cylinder(d = dp, h = len, center = true, $fn = 64);
    translate([0, 0, -len/2]) cylinder(d = dp + P(PIN_HEAD_D), h = P(PIN_HEAD_H), center = true, $fn = 64);
}
// Кільце (втулка, бобишка, розпірка, шайба) — вісь уздовж Y, як у module bushing моделі.
//
// Круглі деталі НЕ дістаються через $sel, хоч і могли б: у тяги `link_boss` стоїть у
// подвійному циклі `for (s = sides()) for (P = [J, Q])`, і $one прибирає лише дзеркало —
// лишаються ДВІ бобишки в різних місцях замість однієї. Тому всі кільця будуються тут
// із тих самих виразів, що й у моделі; числа збігаються з її echo(BOM_ROUND).
module make_ring(od, id, len) {
    rotate([90, 0, 0]) difference() {
        cylinder(d = od, h = len, center = true, $fn = 96);
        cylinder(d = id, h = len + 2, center = true, $fn = 96);
    }
}
// Плита колони — post_schematic() без пальців A і C (вони друкуються окремо)
module make_post_plate() {
    rotate([90, 0, 0]) difference() {
        hull() {
            cylinder(d = 110, h = 12, center = true, $fn = 96);
            translate([C_w[0], C_w[1], 0]) cylinder(d = 90, h = 12, center = true, $fn = 96);
            translate([0, C_w[1] - 150, 0]) cylinder(d = 110, h = 12, center = true, $fn = 96);
        }
        cylinder(d = pin_A, h = 20, center = true, $fn = 96);
        translate([C_w[0], C_w[1], 0]) cylinder(d = boom_cyl_pin, h = 20, center = true, $fn = 96);
    }
}
// Гідроциліндр: у моделі корпус суцільний. Тут у ньому глухий канал під шток.
//   корпус займає X ∈ [eye_len, eye_len + body_L], body_L = closed - 2*eye_len - 30
//   зведений циліндр заганяє шток на (stroke + 20) — звідси глибина stroke + 40
module make_cyl_body(bore, rod, closed, stroke, pin, wall = 5, eye_len = 45) {
    body_L = closed - 2*eye_len - 30;
    depth  = stroke + 40;
    assert(depth < body_L - 20, "канал під шток глибший за гільзу");
    difference() {
        hyd_cyl_part("body", bore, rod, closed, stroke, pin, wall, eye_len);
        translate([eye_len + body_L - depth, 0, 0]) rotate([0, 90, 0])
            cylinder(d = rod + P(FIT_SLIDE), h = depth + eps, $fn = 96);
    }
}

// -----------------------------------------------------------------------------
//  Вибір компонента
// -----------------------------------------------------------------------------
// own != "" — компонент дістається з вузла механізмом самої моделі:
// $sel лишає одну деталь, $one — одну з дзеркальної пари.
module from_assembly() { $sel = pp; $one = true; part_by_name(own); }
module bk_side_one() { $sel = "bk_side"; $one = true; part_by_name("bucket"); }

if (own != "") lay() from_assembly();

// Труби — у власній системі, віссю вздовж +X (як для розгорток ескізів)
// Знак на трубах — на обох бічних стінках: +Y лягає догори (ori = y), −Y — на стіл
else if (pp == "tube_boom_seg1") lay() branded("boom_seg1") tube_local("boom_seg1");
else if (pp == "tube_boom_seg2") lay() tube_local("boom_seg2");
else if (pp == "tube_stick")     lay() branded("stick") tube_local("stick");

// Знак на обох гранях: одна з них друкується на столі — там виїмка трохи грубіша, це нормально
else if (pp == "post_plate")     lay() branded("post_plate") make_post_plate();

// Боковини ковша — дві РІЗНІ деталі, хоча в моделі це одна дзеркальна пара: логотип
// іде на зовнішню грань кожної. $one дає ліву (+Y машини, якщо дивитись від колони на
// ківш), вона лягає зовнішньою гранню догори як є. Права — справжня права (дзеркало по Y
// моделі, зі своїм знаком), перевернута зовнішньою гранню догори: поворот 180° навколо X.
else if (pp == "bk_side_L") lay() branded("bk_side", 1) bk_side_one();
else if (pp == "bk_side_R") lay() rotate([180, 0, 0]) branded("bk_side", -1) mirror([0, 1, 0]) bk_side_one();

// Круглі. Розміри — ті самі вирази, що в моделі; звірено з її echo(BOM_ROUND).
else if (pp == "A_bushing")   lay() make_ring(bush_od_main,     pin_A,        boom_foot_boss_len);
else if (pp == "B_bushing")   lay() make_ring(bush_od_main,     pin_B,        stick_pack_w);
else if (pp == "E_bushing")   lay() make_ring(bushE_od,         pin_E,        stick_tube_w + 2*plate_boss);
else if (pp == "R_bushing")   lay() make_ring(bush_od_small,    pin_R,        stick_tube_w + 2*plate_boss);
else if (pp == "G_boss")      lay() make_ring(stick_cyl_pin + 14, stick_cyl_pin + 0.5, (stick_tube_w - clevis_gap_25)/2);
else if (pp == "J_boss")      lay() make_ring(pin_JQ + 16,      pin_JQ + 0.5, (link_w_in - clevis_gap_25)/2);
else if (pp == "link_boss")   lay() make_ring(link_boss_od,     pin_JQ + 0.5, link_boss_len);
else if (pp == "bk_boss_E")   lay() make_ring(bucket_boss_E_od, pin_E + 0.5,  bucket_boss_E_len);
else if (pp == "bk_spacer_Q") lay() make_ring(bush_od_small,    pin_JQ + 0.5, link_w_in);
else if (pp == "washer_B")    lay() make_ring(bush_od_main + 10, pin_B + 0.5, (boom_tube_w - stick_pack_w)/2);
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

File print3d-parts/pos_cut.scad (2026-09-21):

// Контури деталей у перерізі — для креслення «де саме стають накладні деталі».
// Модель підключається як бібліотека і НЕ змінюється.
//
//   openscad -o out.svg -D 'part="none"' -D 'own="boom"' -D 'k="F_tower"' -D 'ycut=19.5' pos_cut.scad
//   openscad -o geo.echo -D 'part="none"' -D 'k=""' pos_cut.scad      // тільки числа
//
// projection(cut=true) ріже площиною z=0, а пластини вузлів лежать у площині XZ
// (товщина — уздовж Y). Тому спершу translate підсуває потрібний зріз у y=0, і лише
// потім rotate([90,0,0]) кладе його на z=0. Зворотний порядок дає порожній файл:
// поворот уже переніс Y у Z, і зсув по Y нічого не ріже. На деталях на всю ширину
// (ycut = 0) помилка непомітна — саме тому її легко не побачити.

include <../scad/excavator_boom.scad>
assert(!is_undef(boom_tube_h) && !is_undef(cover_half), "scad/excavator_boom.scad не підключився");

k = "";        // ключ $sel деталі
own = "boom";  // вузол, у якому вона живе
ycut = 0;      // на якій відстані вздовж Y брати переріз

if (k == "") {
    echo(GEO = [
        // системи координат вузлів
        ["alpha1", boom_alpha1],                 // нахил 1-го сегмента до хорди
        ["u2_ang", boom_alpha1 - boom_bend],     // нахил 2-го сегмента
        ["K", K_l], ["D_org", D_org],
        ["F_hole", F_l], ["D_hole", D_l],
        ["H_hole", H_s], ["sH", bucket_cyl_sH],
        ["E_hole", [0, 0]], ["Q_hole", bucket_ear],
        ["bk_top_x", bucket_top_x], ["bk_lip_y", bucket_lip_y],
        // поверхні, на які стають накладні деталі (у системі свого вузла)
        ["surf_F", boom_tube_h/2 + plate_gusset],
        ["surf_D", -boom_tube_h/2 - plate_boss],
        ["surf_H", stick_tube_h/2 + plate_boss],
        // проміжки між пластинами пар, товщина пластини
        ["gap_F", clevis_gap_25], ["gap_D", clevis_gap_30],
        ["gap_H", clevis_gap_25], ["gap_E", link_w_in],
        ["plate", plate_clevis], ["ear_t", bucket_ear_t],
        // ширина й товщина пластини-бази
        ["base_F", [boom_tube_w, plate_gusset]],
        ["base_D", [boom_tube_w, plate_boss]],
        ["base_H", [stick_tube_w, plate_boss]],
        ["base_E", [bucket_width, bucket_top_t]]]);
} else {
    // k = "*" — без фільтра $sel: зріз крізь УВЕСЬ вузол на одній площині.
    // Саме так перевіряють, чи деталі справді стикаються: окремі зрізи на різних
    // площинах цього не показують.
    projection(cut = true) rotate([90, 0, 0]) translate([0, -ycut, 0]) {
        $sel = (k == "*") ? "" : k;
        $one = (k != "*");
        part_by_name(own);
    }
}

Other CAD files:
latest/dxf/D_clevis.dxf
latest/dxf/H_clevis.dxf
print3d/print_parts.scad
_deprecated/print3d_deprecated/print_parts.scad
_deprecated/print3d_deprecated/stl/01_post_plate_x2.stl
_deprecated/print3d_deprecated/stl/02_boom_x1.stl
_deprecated/print3d_deprecated/stl/03_stick_x1.stl
_deprecated/print3d_deprecated/stl/04_bucket_x1.stl
_deprecated/print3d_deprecated/stl/05_rocker_plate_x2.stl
_deprecated/print3d_deprecated/stl/06_link_plate_x2.stl
_deprecated/print3d_deprecated/stl/07_cyl_boom_body_x1.stl
_deprecated/print3d_deprecated/stl/08_cyl_boom_rod_x1.stl
_deprecated/print3d_deprecated/stl/09_cyl_stick_body_x1.stl
_deprecated/print3d_deprecated/stl/10_cyl_stick_rod_x1.stl
_deprecated/print3d_deprecated/stl/11_cyl_bucket_body_x1.stl
_deprecated/print3d_deprecated/stl/12_cyl_bucket_rod_x1.stl
_deprecated/print3d_deprecated/stl/13_bush_A_x1.stl
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

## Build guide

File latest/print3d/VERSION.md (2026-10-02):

# V006.2-2026-10-02-2125

> Друкований набір 1:5 машини `V006-2026-09-29-1841`. Згенеровано `print3d-parts/make.sh` — руками не правити.
> Масштабна модель, не іграшка і не проєктна документація; див. `SAFETY.md`.

- Дата: 2026-10-02 21:28
- Git (база на момент збирання): 609e6bf (Print kit: per-part visibility checkboxes in the M5 cylinder model) + незакомічені зміни робочого дерева
- Зміни: M5-циліндри: датчики (SS41F, SS49E) винесено в sensors.py, перероблено m5_cyl.scad, оновлено CALC і README

- `stl/<тека>/` — одна тека = одне завдання слайсера (колір · висота шару · підпори), пояснення — у `print3d-parts/README.md`
- `BOM.md` — специфікація з виміряних STL; `DRIVE.md` — привід циліндрів гвинтом M5
- `m5_cylinders/` — циліндри на шпильці M5 з моторедуктором N20: `stl/`, `img/`, `CALC.md`, `WIRING.svg`, `SENSORS.svg` (як влаштовано — `print3d-parts/m5_cylinders/README.md`)
- `sheets/SHEETS.pdf` — аркуші розкладки 1:1 для сортування й склеювання; `sheets/sheets.json` — усі числа (прев'ю сторінок — у `build/sheets-png/`, не в git)

---
<sub>Ihor Ivaniuk · @IBITLAB</sub>

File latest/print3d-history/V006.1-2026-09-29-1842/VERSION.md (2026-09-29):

# V006.1-2026-09-29-1842

> Друкований набір 1:5 машини `V006-2026-09-29-1841`. Згенеровано `print3d-parts/make.sh` — руками не правити.
> Масштабна модель, не іграшка і не проєктна документація; див. `SAFETY.md`.

- Дата: 2026-09-29 18:43
- Git (база на момент збирання): bd6bd8a (Move the reference documents from the root to docs/) + незакомічені зміни робочого дерева
- Зміни: з нової версії машини V006-2026-09-29-1841

- `stl/<тека>/` — одна тека = одне завдання слайсера (колір · висота шару · підпори), пояснення — у `print3d-parts/README.md`
- `BOM.md` — специфікація з виміряних STL; `DRIVE.md` — привід циліндрів гвинтом M5
- `m5_cylinders/` — циліндри на шпильці M5 з моторедуктором N20: `stl/`, `img/`, `CALC.md` (як влаштовано — `print3d-parts/m5_cylinders/README.md`). Дописано вручну до зібраного V006.1: сам набір не змінювався, тека зібрана `print3d-parts/m5_cylinders/make.sh`
- `sheets/SHEETS.pdf` — аркуші розкладки 1:1 для сортування й склеювання; `sheets/sheets.json` — усі числа (прев'ю сторінок — у `build/sheets-png/`, не в git)

---
<sub>Ihor Ivaniuk · @IBITLAB</sub>

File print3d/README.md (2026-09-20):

# Друкований набір «міні-екскаватор» 1:7

Збірна масштабна модель робочого обладнання з тієї самої моделі, з якої виходять
креслення: **одна колона, стріла, рукоять, ківш, коромисло, тяги, три робочі
гідроциліндри, чотири втулки й одинадцять пальців**. Збирається як конструктор,
розбирається назад, важільна система рухається.

> **УВАГА.** Модель, розрахунки й ця підготовка до друку згенеровані штучним інтелектом.
> Інженер їх не перевіряв, метал не різаний, машина не збудована й не випробувана.
> Надрукований набір — демонстрація кінематики, а не іграшка й не документація.
> Пальці Ø3–4 мм — дрібні деталі, не для дітей. Див. `SAFETY.md` у корені.

```
print3d/make.sh          # ≈1 хв: 27 STL у print3d/stl/, перевірка, BOM.md
```

Склад набору — `parts.tsv`, специфікація з виміряними габаритами — [BOM.md](BOM.md).

## Чому 1:7

Обмеження — найбільша деталь на столі 250×250×250. Стріла в моделі 1674.7 мм:

| Масштаб | Стріла, мм | Влазить |
|---|---:|---|
| 1:6 | 279.1 | ні |
| **1:7** | **239.2** | **так, запас 10.8 мм** |
| 1:8 | 209.3 | так, із запасом |

1:7 — найбільший цілий масштаб, за якого стріла ще влазить. Запас малий: якщо
принтер має справжні 250 мм лише по діагоналі або ви друкуєте зі спіднею спідницею,
беріть 1:8 — у `print_parts.scad` змінна `SC`, решта перерахується сама.

## Орієнтація: чому все лежить «на боці»

Усі вузли цієї машини призначені в одній площині, а **всі осі шарнірів паралельні
одній осі** (Y моделі). Тому кожна деталь кладеться так, щоб Y став вертикаллю:

- отвори під пальці стають вертикальними — друкуються круглими, без провисання;
- пластини лягають горизонтально, шар за шаром, а не стоять на ребрі;
- кожен шар — майже той самий контур, тобто мінімум звисів.

Це робить `module lay()`. Деталь не опускається на нуль по Z — слайсер це робить сам.

## Що друк робить із цими деталями

### Тонкі стінки

При 1:7 і соплі 0.4 мм (дві лінії = 0.8 мм):

| Елемент | У металі | Надруковано | Оцінка |
|---|---:|---:|---|
| стінка труби стріли й рукояті | 5 мм | **0.71 мм** | менше двох ліній — одна тонка стінка |
| обичайка ковша | 5 мм | **0.71 мм** | те саме |
| боковина ковша | 6 мм | 0.86 мм | дві лінії, нормально |
| щока, косинка | 8 мм | 1.14 мм | добре |
| накладка | 10 мм | 1.43 мм | добре |
| вилка | 12 мм | 1.71 мм | добре |

0.71 мм — вище за сопло, тож нічого не зникне, але слайсер покладе туди одну лінію
змінної ширини (Arachne). Труби й ківш вийдуть помітно слабшими за решту. Хочете
міцніше — друкуйте 1:5…1:6 частинами або збільшіть ширину екструзії до 0.6 мм.

### Деталі в повітрі: містки проти полиць

Перевірка `check_print.py` рахує окремо **схили** (опуклі дуги, друкуються з
провисанням і без підпор) і **полиці** — майже горизонтальні поверхні, під якими
порожнеча. У стріли й рукояті полиць начебто 27 %, і це число оманливе:

**Найбільша «полиця» стріли — 3162 мм² на висоті 12.5 мм — це стеля порожнистої
труби.** Переріз надрукованого STL показує метал лише на −5.71…−5.00 і 5.00…5.71:
стінки 0.71 мм, а між ними порожнина 10 мм заввишки і 16.3 мм завширшки. Стеля
спирається на обидві стінки, тобто це **місток 16.3 мм**, який FDM кладе без підпор.
У рукояті так само — місток 12.9 мм.

Звідси головне правило:

> **Підпори — тільки «від столу» (support on build plate only).**
> Підпора «всюди» заповнить порожнини всередині труб стріли й рукояті, і дістати її
> звідти буде вже неможливо: труба закрита з усіх боків.

Справжні полиці, яким підпора потрібна, — на висоті **0.5–1.5 мм** над столом: це
низ пластин, вужчих за найширше місце деталі (деталі симетричні відносно середньої
площини, тож усе вужче за вилку B висить над столом). Підпора від столу бере їх і
відламується легко.

Окремий випадок — **ківш**: верхня боковина (0.86 мм) накриває нутро ковша полицею
**52 × 37 мм** (виміряно перерізом на 0.9 мм нижче верху). Це вже не місток: стінок
під серединою нема. Або ставте підпору всередину — вона доступна через розкриту пащу
ковша, — або змиріться з провисанням верхньої боковини.

Хто хоче взагалі без підпор: стріла, рукоять і ківш симетричні відносно середньої
площини. Розріжте їх у слайсері навпіл по цій площині, покладіть половинки плоскою
гранню вниз і склейте — звисів не лишиться зовсім, але з'являться шви.

### Що друкується без жодної підпори

Плити колони, пластини коромисла й тяг (0 % полиць, уся площа на столі), усі чотири
втулки й усі одинадцять пальців. Пальці стоять вертикально голівкою на столі; голівка
Ø+1.6 мм дає і площу зчеплення, і упор, щоб палець не провалювався у з'єднанні.

## Посадки

Жоден отвір у моделі не перероблявся — **увесь зазор знятий із пальця**:

| З'єднання | Зазор, мм | Де задано |
|---|---:|---|
| палець у отворі й у втулці | 0.40 | `FIT_PIN` — віднімається від діаметра пальця |
| втулка у гнізді вузла | 0.15 | `FIT_BUSH` — додається до розточки |
| шток у гільзі циліндра | 0.35 | `FIT_SLIDE` — додається до каналу |

Друковані діаметри: пальці Ø30 → **3.89 мм**, Ø25 → **3.17 мм**; втулки A, B, E —
Ø9.43/4.29, втулка R — Ø6.43/4.29.

Якщо ваш принтер «повнить» і палець не лізе — збільшуйте `FIT_PIN` до 0.5; якщо
з'єднання бовтається — зменшуйте до 0.25. Втулка має заходити від руки з невеликим
зусиллям; вийшла вільною — крапля клею.

## Гідроциліндри справді ходять

У моделі корпус циліндра суцільний — вона показує машину, а не механізм. Тут у ньому
просвердлено глухий канал Ø(шток + 0.35), і шток у нього заходить:

| Циліндр | Канал, мм | Захід зведеного, мм | Захід розкритого, мм |
|---|---:|---:|---:|
| стріли | 77.1 | 74.3 | 2.9 |
| рукояті | 62.9 | 60.0 | 2.9 |
| ковша | 48.6 | 45.7 | 2.9 |

Перевірено променем крізь надрукований STL, не розрахунком «на папері».

**Межа:** на повному вильоті шток сидить у гільзі лише на 2.9 мм і буде хитатися —
це відповідає реальному циліндру на кінці ходу. Не виводьте на самий кінець.

## Чого в наборі НЕМА і чому

- **Упорні шайби осі B** (в металі 2 мм) — при 1:7 це 0.29 мм, тонше за один шар.
  Їхню роль бере на себе зазор пальця.
- **Приварні бобишки** G, J, link_boss, bk_boss_E і розпірна втулка Q лишилися
  всередині своїх вузлів: за специфікацією моделі вони приварені (втулка Q — до обох
  вух ковша), тож окремими деталями їм нема на чому триматися.
- **Print-in-place не застосовано свідомо.** При 1:7 зазор 0.3–0.4 мм — це десята
  частина діаметра пальця; надрукований на місці шарнір вийшов би або злиплим, або
  бовтким. Гірше інше: палець, надрукований усередині втулки, вимагає підпор там, де
  їх уже не дістати. Окремі пальці дають і кращий шарнір, і можливість розібрати.

## Друк: налаштування

| | |
|---|---|
| сопло | 0.4 мм |
| шар | 0.2 мм (0.12 для пальців і втулок — чистіший циліндр) |
| периметри | 3 (труби й ківш усе одно вийдуть в одну лінію) |
| заповнення | 15–20 % |
| підпори | **тільки від столу**; всередину ковша — за бажанням |
| brim | для пальців і втулки R (контакт 18–24 мм²) |
| матеріал | PLA або PETG; ≈86 г при 100 % заповненні, реально близько 40–50 г |

Деталі складаються з кількох тіл, що прилягають гранями (стріла — 3, гільзи — 3):
так побудована сама модель, «пластини прилягають, але не перетинаються». Слайсер
зливає їх при нарізанні. У Cura ввімкніть *Union overlapping volumes*, у
PrusaSlicer нічого робити не треба. Повідомлення перевірки про «36 ребер у понад
двох гранях» — це ті самі спільні грані, а не дефект.

## Порядок збирання

1. Втулки **A, B, E, R** — у свої гнізда (A і B — у стрілу й рукоять, E і R — у кінець рукояті).
2. Стріла між двома плитами колони, палець **A**.
3. Гільза циліндра стріли вушком на колону — палець **C**; шток у вилку D стріли — палець **D**.
4. Рукоять у вилку B стріли — палець **B**.
5. Циліндр рукояті: база на вежу F стріли — палець **F**; шток на п'яту рукояті — палець **G**.
6. Дві пластини коромисла на кінець рукояті — палець **R**.
7. Ківш на кінець рукояті — палець **E**.
8. Дві тяги: одним кінцем на вісь **J** коромисла, другим на вухо ковша — палець **Q**.
9. Циліндр ковша: база на вилку H рукояті — палець **H**; шток разом із коромислом і тягами — палець **J**.

Пальці заходять голівкою вперед з одного боку.

**Пози набір не тримає.** Усі шарніри вільні, штоки ходять без тертя — під власною
вагою машина складеться. Для показу або зменшіть `FIT_PIN` до 0.25, або притримуйте
руками, або зафіксуйте потрібну позу краплею клею в шарнірах.

## Як це зроблено

`print_parts.scad` підключає `scad/excavator_boom.scad` як бібліотеку з `part="none"`
і збирає деталі з її ж модулів. **Модель не змінюється жодним рядком** — зміниться
вона, зміниться й набір. Звідси й обмеження: геометрія тут рівно та, що в машині,
плюс розточки під втулки, канал у гільзі та зазор на пальці.

Ця тека лежить не у `versions/`, бо це не етап збирання машини, а окремий виріб,
знятий із замороженої версії `V001-2026-09-20-0505`. Вміст `print3d/stl/` —
згенерований (1.5 МБ); його можна не тримати в git, бо `make.sh` відтворює його за хвилину.

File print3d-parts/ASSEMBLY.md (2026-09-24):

# Складання набору 1:5: що до чого приклеюється

> Згенеровано `make.sh`. Порядок з'єднань — `assembly.tsv`, габарити —
> ВИМІРЯНІ зі STL, назви й розміри в металі — `parts.tsv` (з `echo(BOM_*)` моделі).
>
> **УВАГА:** масштабна модель, згенерована штучним інтелектом. Метал не різаний,
> машину не збудовано. Порядок відповідає порядку ЗВАРЮВАННЯ в металі, але
> інженер його не перевіряв. Див. `SAFETY.md`.

Клей — той самий шов: у кроках 1–5 з'єднання нерухомі. Рухомими лишаються
тільки пальці кроку 7 і штоки циліндрів.

## Як не сплутати схожі деталі

Пари, у яких усі три габарити збігаються з точністю до 2 мм — на око їх не розрізнити, міряйте штангенциркулем:

| Деталь | Габарит, мм | Деталь | Габарит, мм | Різниця | Чим відрізняються |
|---|---|---|---|---:|---|
| `19_bk_side_L` | 67.0 × 52.1 × 1.2 | `19_bk_side_R` | 67.0 × 52.1 × 1.2 | — | **дзеркальні — ліва й права, логотип назовні** |
| `43_pin_A` | Ø7.2 × 36.9 | `44_pin_C` | Ø7.2 × 36.9 | — | **однакові — взаємозамінні** |
| `48_pin_F` | Ø6.2 × 14.7 | `50_pin_H` | Ø6.2 × 14.7 | — | **однакові — взаємозамінні** |
| `51_pin_J` | Ø6.2 × 40.1 | `52_pin_Q` | Ø6.2 × 40.1 | — | **однакові — взаємозамінні** |
| `36_R_bushing` | Ø9.0 × 16.0 | `41_bk_spacer_Q` | Ø9.0 × 16.4 | 0.4 | довжина: 16.0 проти 16.4 |
| `34_B_bushing` | Ø13.2 × 15.2 | `35_E_bushing` | Ø13.2 × 16.0 | 0.8 | довжина: 15.2 проти 16.0 |
| `46_pin_D` | Ø7.2 × 15.3 | `48_pin_F` | Ø6.2 × 14.7 | 1.0 | Ø: 7.2 проти 6.2 |
| `46_pin_D` | Ø7.2 × 15.3 | `50_pin_H` | Ø6.2 × 14.7 | 1.0 | Ø: 7.2 проти 6.2 |
| `49_pin_G` | Ø6.2 × 19.7 | `53_pin_R` | Ø7.2 × 20.9 | 1.0 | Ø: 6.2 проти 7.2 |
| `38_J_boss` | Ø8.2 × 5.5 | `39_link_boss` | Ø10.0 × 5.0 | 1.8 | Ø: 8.2 проти 10.0 |
| `36_R_bushing` | Ø9.0 × 16.0 | `46_pin_D` | Ø7.2 × 15.3 | 1.8 | Ø: 9.0 проти 7.2 |
| `41_bk_spacer_Q` | Ø9.0 × 16.4 | `46_pin_D` | Ø7.2 × 15.3 | 1.8 | Ø: 9.0 проти 7.2 |
| `04_gusset` | 113.1 × 48.1 × 1.6 | `26_post_plate` | 112.0 × 50.0 × 2.4 | 0.8 | товщина: 1.6 проти 2.4 |

Габарити тут — у позі друку (деталь лежить так, як вийшла з принтера),
відсортовані від найбільшого до найменшого, щоб порівняння не залежало від того,
яким боком ви взяли деталь.

## Де саме стають накладні деталі

Більшість деталей упирається в кромку або в отвір — їх не поставиш інакше.
Але чотири приварюються ПОСЕРЕД пластини, нічим не впираючись: вежа F,
вилка D, вилка H і вуха ковша. На око їх не виставити.

Числа ВИМІРЯНІ зі слідів деталей на базових пластинах — не взяті з коду
моделі й не вписані руками. Праворуч та сама відстань на надрукованій
деталі. Це ті самі числа, що стоять підписами на кресленні.

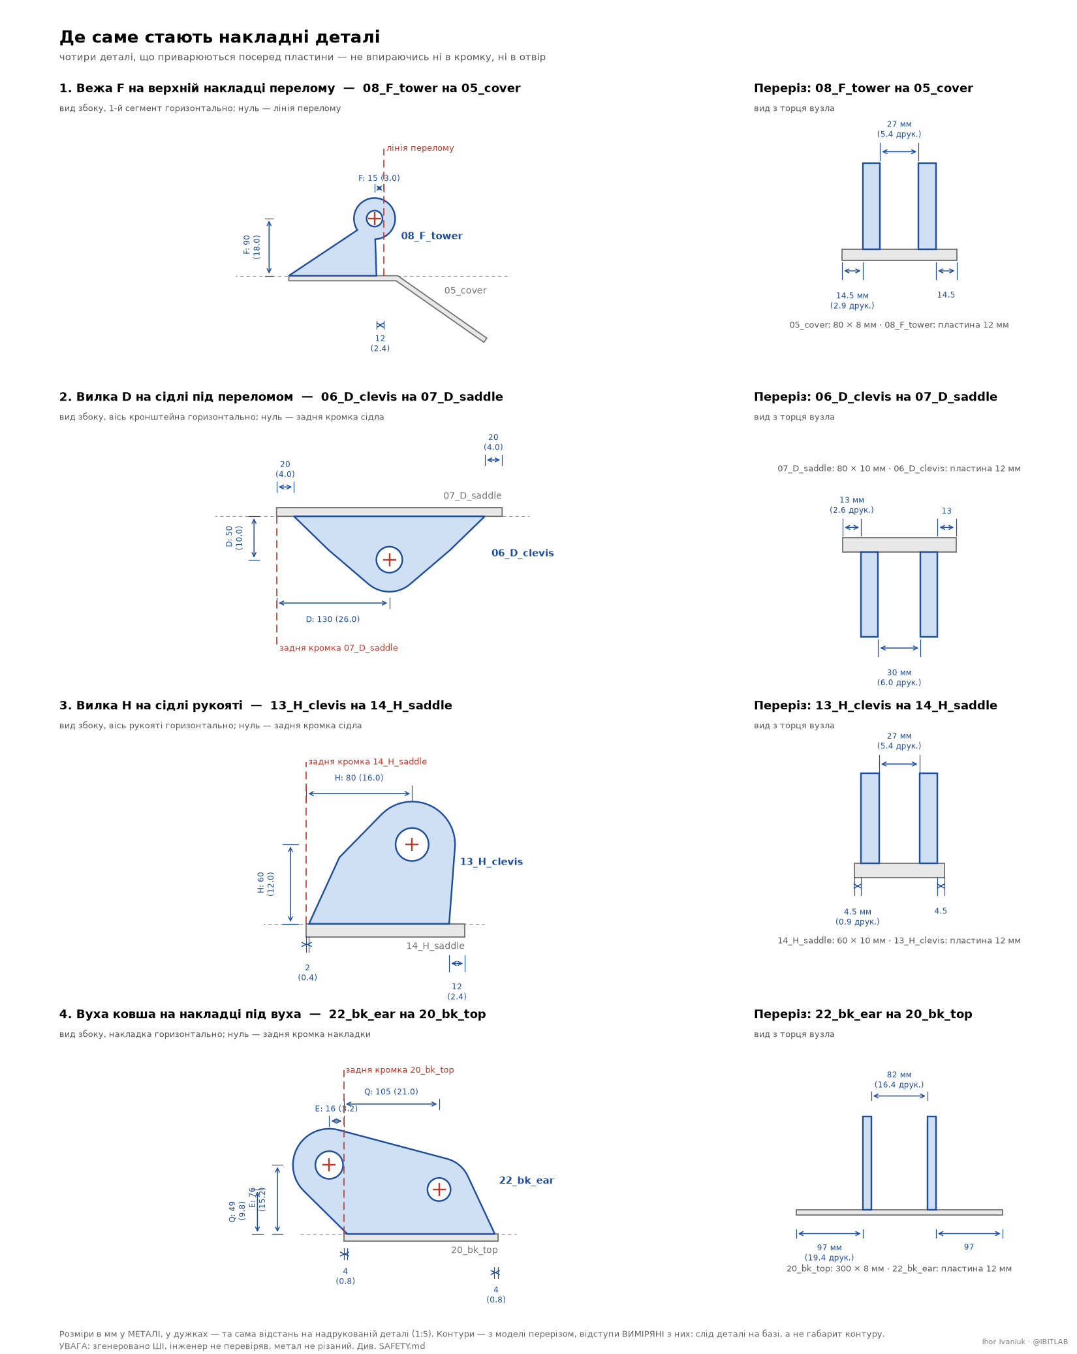
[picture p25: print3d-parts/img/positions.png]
прив'язки накладних деталей


**`08_F_tower` на `05_cover`**

| Розмір | У металі, мм | Надруковано, мм |
|---|---:|---:|
| задня кромка деталі від задньої кромки накладки | 0 | 0.00 |
| передня кромка деталі не доходить до лінії перелому на | 12 | 2.40 |
| центр отвору F назад від лінії перелому | 15 | 3.00 |
| центр отвору F від поверхні накладки | 90 | 18.00 |
| проміжок між пластинами пари | 27 | 5.40 |
| від бічної кромки накладки до зовнішньої грані пластини | 14.5 | 2.90 |

**`06_D_clevis` на `07_D_saddle`**

| Розмір | У металі, мм | Надруковано, мм |
|---|---:|---:|
| відступ від задньої кромки сідла | 20 | 4.00 |
| відступ від передньої кромки сідла | 20 | 4.00 |
| центр отвору D від задньої кромки сідла | 130 | 26.00 |
| центр отвору D від поверхні сідла | 50 | 10.00 |
| проміжок між пластинами пари | 30 | 6.00 |
| від бічної кромки сідла до зовнішньої грані пластини | 13 | 2.60 |

**`13_H_clevis` на `14_H_saddle`**

| Розмір | У металі, мм | Надруковано, мм |
|---|---:|---:|
| відступ від задньої кромки сідла | 2 | 0.40 |
| відступ від передньої кромки сідла | 12 | 2.40 |
| центр отвору H від задньої кромки сідла | 80 | 16.00 |
| центр отвору H від поверхні сідла | 60 | 12.00 |
| проміжок між пластинами пари | 27 | 5.40 |
| від бічної кромки сідла до зовнішньої грані пластини | 4.5 | 0.90 |

**`22_bk_ear` на `20_bk_top`**

| Розмір | У металі, мм | Надруковано, мм |
|---|---:|---:|
| відступ від задньої кромки накладки | 4 | 0.80 |
| відступ від передньої кромки накладки | 4 | 0.80 |
| центр отвору E позаду задньої кромки накладки | 16 | 3.20 |
| центр отвору E від поверхні накладки | 76 | 15.20 |
| центр отвору Q від задньої кромки накладки | 105 | 21.00 |
| центр отвору Q від поверхні накладки | 49 | 9.80 |
| проміжок між пластинами пари | 82 | 16.40 |
| від бічної кромки накладки до зовнішньої грані пластини | 97 | 19.40 |

Усі чотири — дзеркальні пари й стоять симетрично середній площині вузла,
тому «від бічної кромки до зовнішньої грані» однакове з обох боків.
Відступи міряються по СЛІДУ деталі на базі: бобишка навколо отвору звисає
за основу (у вежі F на 17.5 мм за лінію перелому, у вуха ковша на 56 мм
позаду накладки), і за габаритом контуру деталь стала б не на місце.

## 1. Стріла

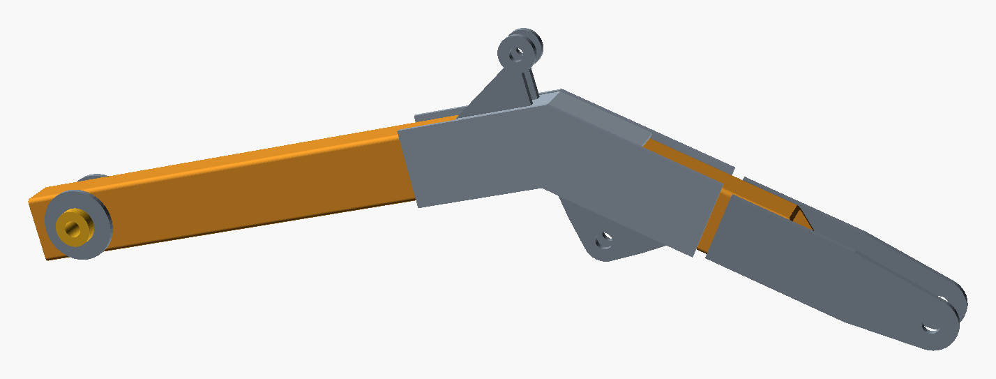
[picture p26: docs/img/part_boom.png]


*вузол цілком*

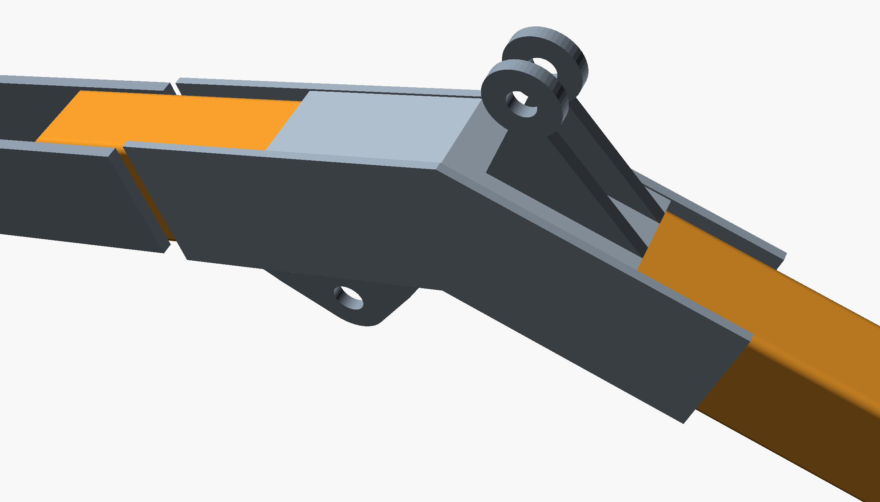
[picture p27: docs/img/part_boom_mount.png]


*перелом зблизька: щоки, накладка, вежа F зверху, сідло і вилка D знизу*

| Крок | Файл | К-сть | Габарит друку, мм | Ескіз | Куди | Як |
|---|---|---:|---|---|---|---|
| 1.1 | `01_tube_boom_seg1` | 1 | 201.8 × 24.0 × 16.0 | [аркуш](../versions/V005-2026-09-24-1519/drawings/png/03_boom_seg1.png) | основа вузла | Покласти отвором Ø66 (вісь A) ліворуч; косий різ 17.5° — на правому торці |
| 1.2 | `02_tube_boom_seg2` | 1 | 119.8 × 24.0 × 16.0 | [аркуш](../versions/V005-2026-09-24-1519/drawings/png/04_boom_seg2.png) | до косого різу сегмента 1 | Косий різ до косого різу — вони й дають перелом 35°; коротша верхня полиця дивиться на вільний кінець |
| 1.3 | `04_gusset` | 2 | 113.1 × 48.1 × 1.6 | [аркуш](../versions/V005-2026-09-24-1519/drawings/png/07_gusset.png) | з обох боків стику труб | Щоки перекривають шов перелому; нижня кромка — урівень із нижньою полицею |
| 1.4 | `05_cover` | 1 | 62.4 × 16.0 × 21.0 | — | зверху на перелом, між щоками | Уже зігнута посередині на 35°, лягає одразу на обидві верхні полиці. На неї потім стане вежа F — див. крок 1.8 |
| 1.5 | `33_A_bushing` | 1 | Ø13.2 × 28.0 | — | в отвір Ø66 сегмента 1 | Наскрізь крізь обидві стінки; виступає з боків порівну — втулка довша за ширину труби |
| 1.6 | `09_A_doubler` | 2 | Ø26.0 × 2.0 | [аркуш](../versions/V005-2026-09-24-1519/drawings/png/10_A_doubler.png) | на бічні стінки труби навколо втулки A | По одній накладці з кожного боку, отвором на втулку |
| 1.7 | `10_B_fork` | 2 | 84.6 × 46.0 × 2.4 | [аркуш](../versions/V005-2026-09-24-1519/drawings/png/11_B_fork.png) | на передній торець сегмента 2, з боків | Дві пластини; між ними потім заходить п'ята рукояті |
| 1.8 | `08_F_tower` | 2 | 27.8 × 31.0 × 2.4 | [аркуш](../versions/V005-2026-09-24-1519/drawings/png/09_F_tower.png) | на верхню накладку перелому | Задня кромка — ВРІВЕНЬ із задньою кромкою накладки, передня не доходить до лінії перелому на 12 мм (2.4 друкованих). Уперед не можна: там проходить корпус циліндра. Решта розмірів — розділ «Де саме стають накладні деталі» |
| 1.9 | `07_D_saddle` | 1 | 52.0 × 16.0 × 2.0 | — | знизу між щоками перелому | Сідло стає врівень із виступами щік. Під нього потім стане вилка D — див. крок 1.10 |
| 1.10 | `06_D_clevis` | 2 | 41.4 × 24.2 × 2.4 | [аркуш](../versions/V005-2026-09-24-1519/drawings/png/08_D_clevis.png) | на сідло D | Відступ 20 мм (4.0 друкованих) від кожного торця сідла, отвір — рівно посередині його довжини, проміжок 30 мм. Решта розмірів — розділ «Де саме стають накладні деталі» |

## 2. Рукоять

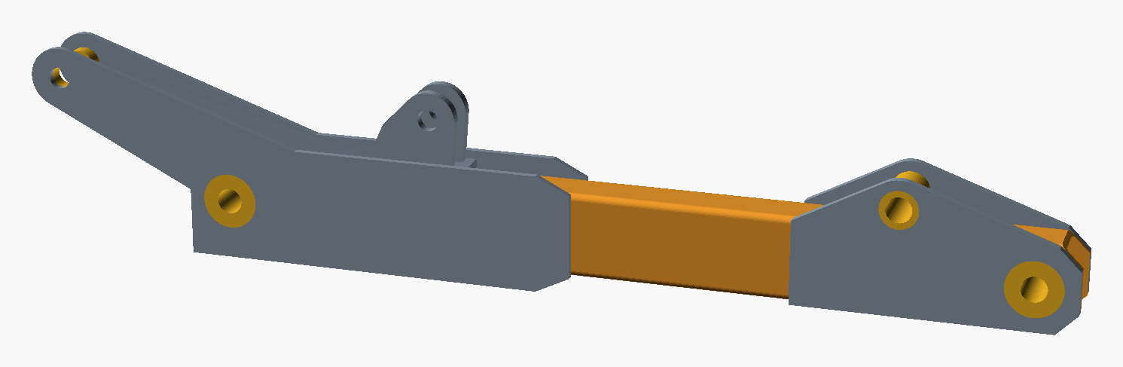
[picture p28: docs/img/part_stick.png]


*вузол цілком*

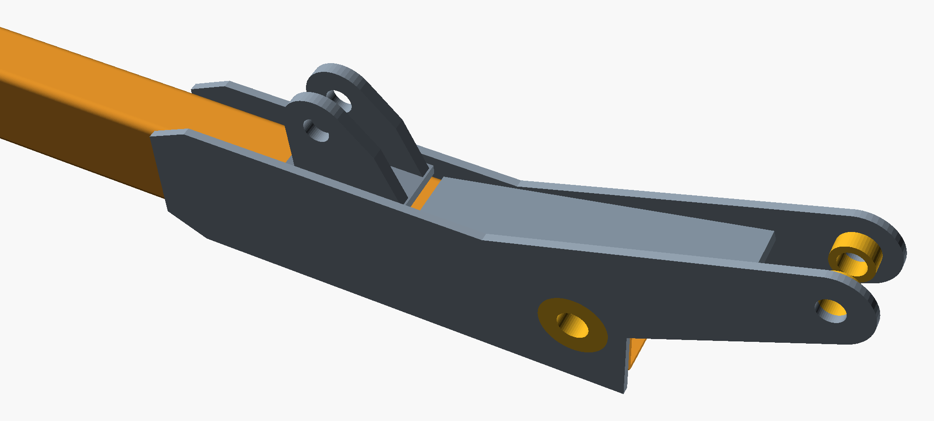
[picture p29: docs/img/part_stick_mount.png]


*п'ята зблизька: щоки, втулка осі B, сідло і вилка H, бобишка осі G*

| Крок | Файл | К-сть | Габарит друку, мм | Ескіз | Куди | Як |
|---|---|---:|---|---|---|---|
| 2.1 | `03_tube_stick` | 1 | 210.0 × 20.0 × 12.0 | [аркуш](../versions/V005-2026-09-24-1519/drawings/png/05_stick.png) | основа вузла | Задній торець — той, де отвір Ø66 за 50 мм від краю (вісь B); другий Ø66 (вісь E) — за 1000 мм |
| 2.2 | `11_cheek` | 2 | 134.3 × 47.7 × 1.6 | [аркуш](../versions/V005-2026-09-24-1519/drawings/png/12_cheek.png) | з боків труби на задньому кінці | Щоки виступають за полиці на 20 мм; саме вони несуть момент циліндра рукояті |
| 2.3 | `12_heel_rib` | 1 | 62.2 × 12.0 × 2.0 | — | між щоками, у п'яті | Ребро замикає п'яту в коробку |
| 2.4 | `34_B_bushing` | 1 | Ø13.2 × 15.2 | — | в отвір Ø66 за 50 мм від заднього торця | Наскрізь крізь трубу і ОБИДВІ щоки |
| 2.5 | `14_H_saddle` | 1 | 24.0 × 12.0 × 2.0 | — | зверху між виступами щік | Сідло під вилку циліндра ковша |
| 2.6 | `13_H_clevis` | 2 | 22.1 × 18.5 × 2.4 | [аркуш](../versions/V005-2026-09-24-1519/drawings/png/13_H_clevis.png) | на сідло H | Стоїть НЕСИМЕТРИЧНО: 2 мм (0.4 друкованих) від задньої кромки сідла, 12 мм (2.4) від передньої — основа тягнеться назад, бо вперед плечей немає, туди лягає корпус циліндра. Решта розмірів — розділ «Де саме стають накладні деталі» |
| 2.7 | `37_G_boss` | 2 | Ø7.8 × 3.3 | — | на щоки ззовні, вісь G | Розпірні втулки, по одній на щоку: вони задають проміжок під вушко штока |
| 2.8 | `15_tip_plate` | 2 | 64.4 × 31.9 × 2.0 | [аркуш](../versions/V005-2026-09-24-1519/drawings/png/14_tip_plate.png) | на передній кінець труби, з боків | Накладки під осі E і R |
| 2.9 | `35_E_bushing` | 1 | Ø13.2 × 16.0 | — | в отвір Ø66 за 1000 мм від заднього торця | Наскрізь крізь трубу і обидві накладки кінця |
| 2.10 | `36_R_bushing` | 1 | Ø9.0 × 16.0 | — | між накладками кінця, над верхньою полицею | Вісь коромисла тримається тільки накладками, труби не торкається |

## 3. Ківш

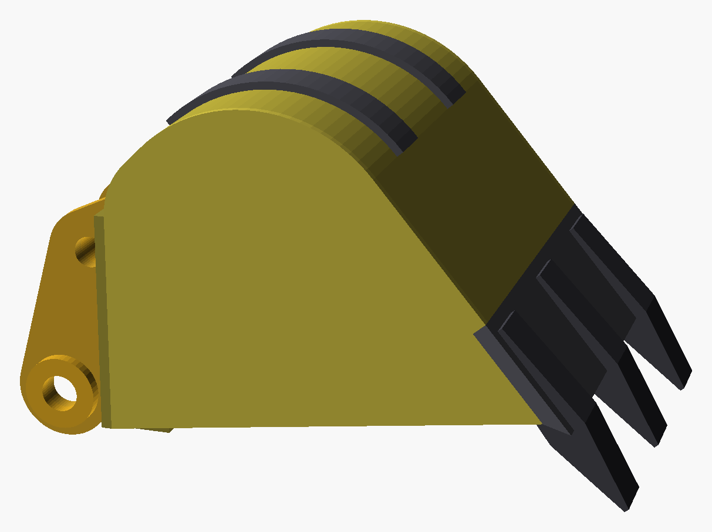
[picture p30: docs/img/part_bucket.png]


*вузол цілком*

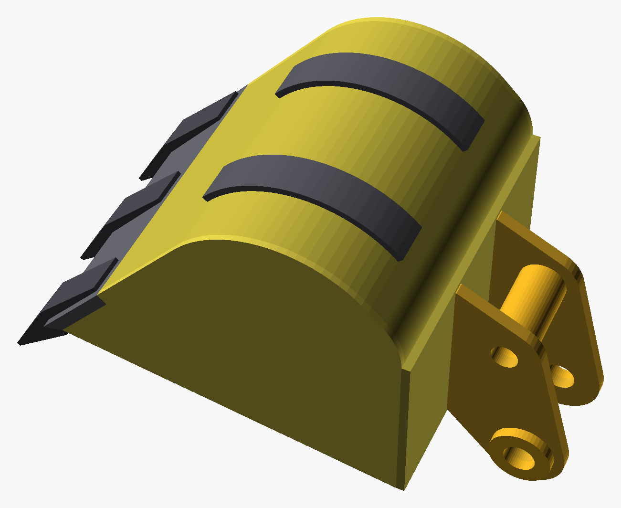
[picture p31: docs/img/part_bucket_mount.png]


*кріплення зблизька: два вуха, розпірка осі Q між ними, бобишки осі E зовні*

| Крок | Файл | К-сть | Габарит друку, мм | Ескіз | Куди | Як |
|---|---|---:|---|---|---|---|
| 3.1 | `18_bk_shell` | 1 | 58.3 × 52.1 × 57.6 | [аркуш](../versions/V005-2026-09-24-1519/drawings/png/06_bk_shell.png) | основа вузла | Уже зігнута: полиця → R55 на 45° → спинка → R115 на 95° → дно; ставити порожниною догори |
| 3.2 | `19_bk_side_L` | 1 | 67.0 × 52.1 × 1.2 | [аркуш](../versions/V005-2026-09-24-1519/drawings/png/17_bk_side.png) | з лівого боку обичайки | По всьому контуру обичайки; логотип — НАЗОВНІ. Ліва — якщо дивитись від колони на ківш |
| 3.3 | `19_bk_side_R` | 1 | 67.0 × 52.1 × 1.2 | [аркуш](../versions/V005-2026-09-24-1519/drawings/png/17_bk_side.png) | з правого боку обичайки | Дзеркальна до лівої: так само по контуру, логотип — НАЗОВНІ |
| 3.4 | `20_bk_top` | 1 | 34.0 × 60.0 × 1.6 | — | на обичайку і верхні кромки боковин | Накладка, на яку потім стануть вуха |
| 3.5 | `21_bk_lip_rib` | 1 | 8.0 × 57.6 × 1.6 | — | під передню кромку верху | Ребро губи |
| 3.6 | `22_bk_ear` | 2 | 23.2 × 44.4 × 2.4 | [аркуш](../versions/V005-2026-09-24-1519/drawings/png/18_bk_ear.png) | на накладку верху | Відступ 4 мм (0.8 друкованих) від кожної кромки накладки; вісь E звисає на 16 мм позаду її задньої кромки. Решта розмірів — розділ «Де саме стають накладні деталі» |
| 3.7 | `41_bk_spacer_Q` | 1 | Ø9.0 × 16.4 | — | між вухами, вісь Q | Приварити до ОБОХ вух — це розпірка, а не втулка обертання |
| 3.8 | `40_bk_boss_E` | 2 | Ø12.0 × 2.0 | — | зовні вух, вісь E | По одній бобишці зовні кожного вуха |
| 3.9 | `23_bk_edge` | 1 | 20.0 × 60.0 × 2.4 | — | на передню кромку дна | Ніж; фаска 34° — догори |
| 3.10 | `24_bk_tooth` | 3 | 22.4 × 26.1 × 8.0 | — | на ніж | Три зуби вилкою охоплюють ніж |
| 3.11 | `25_bk_wear` | 2 | 37.1 × 9.8 × 8.0 | — | знизу на п'яту | Смуги зносу, уже вигнуті по радіусу п'яти |

## 4. Важільна система

| Крок | Файл | К-сть | Габарит друку, мм | Ескіз | Куди | Як |
|---|---|---:|---|---|---|---|
| 4.1 | `16_rocker_plate` | 2 | 71.7 × 15.8 × 2.0 | [аркуш](../versions/V005-2026-09-24-1519/drawings/png/15_rocker_plate.png) | основа коромисла | Дві пластини: отвір R сідає на рукоять, отвір J — до штока циліндра ковша |
| 4.2 | `38_J_boss` | 2 | Ø8.2 × 5.5 | — | зсередини пластин коромисла, вісь J | Упритул до вушка циліндра — без них палець J працює на згин |
| 4.3 | `17_link_plate` | 2 | 54.8 × 63.3 × 2.0 | [аркуш](../versions/V005-2026-09-24-1519/drawings/png/16_link_plate.png) | основа тяги | Дві пластини |
| 4.4 | `39_link_boss` | 4 | Ø10.0 × 5.0 | — | зовні пластин тяги, осі J і Q | По дві бобишки на пластину, чотири на вузол |

## 5. Колона

| Крок | Файл | К-сть | Габарит друку, мм | Ескіз | Куди | Як |
|---|---|---:|---|---|---|---|
| 5.1 | `26_post_plate` | 2 | 50.0 × 112.0 × 2.4 | — | схема опори | Дві плити з осями A і C. Це не готовий вузол: рами причепа в моделі ще немає |

## 6. Гідроциліндри

| Крок | Файл | К-сть | Габарит друку, мм | Ескіз | Куди | Як |
|---|---|---:|---|---|---|---|
| 6.1 | `27_cyl_boom_body` | 1 | 130.8 × 18.0 × 15.2 | — | — | Гільза циліндра стріли Ø63, канал під шток глухий |
| 6.2 | `28_cyl_boom_rod` | 1 | 124.8 × 11.6 × 8.0 | — | у гільзу циліндра стріли | Шток має ходити — НЕ клеїти |
| 6.3 | `29_cyl_stick_body` | 1 | 110.3 × 14.8 × 12.0 | — | — | Гільза циліндра рукояті Ø50 |
| 6.4 | `30_cyl_stick_rod` | 1 | 104.3 × 10.6 × 5.0 | — | у гільзу циліндра рукояті | Шток має ходити — НЕ клеїти |
| 6.5 | `31_cyl_bucket_body` | 1 | 92.3 × 14.8 × 12.0 | — | — | Гільза циліндра ковша Ø50 |
| 6.6 | `32_cyl_bucket_rod` | 1 | 84.3 × 10.6 × 5.0 | — | у гільзу циліндра ковша | Шток має ходити — НЕ клеїти |

## 7. Складання на пальцях

| Крок | Файл | К-сть | Габарит друку, мм | Ескіз | Куди | Як |
|---|---|---:|---|---|---|---|
| 7.1 | `43_pin_A` | 1 | Ø7.2 × 36.9 | — | стріла на плити колони | Крізь втулку A; голівка пальця заходить першою |
| 7.2 | `44_pin_C` | 1 | Ø7.2 × 36.9 | — | база циліндра стріли на плити колони | НЕ плутати з пальцем D: цей проходить крізь обидві плити колони, тож удвічі довший (Ø30×182 проти Ø30×74). За довжиною він однаковий із пальцем A |
| 7.3 | `45_pin_B` | 1 | Ø7.2 × 26.1 | — | п'ята рукояті у вилку B стріли | Разом із шайбами наступного кроку |
| 7.4 | `42_washer_B` | 2 | Ø15.2 × 0.4 | — | на палець B, з боків пакета рукояті | Вибирають зазор між вилкою 80 і пакетом 76 — по 2 мм на бік |
| 7.5 | `46_pin_D` | 1 | Ø7.2 × 15.3 | — | шток циліндра стріли у вилку D | — |
| 7.6 | `48_pin_F` | 1 | Ø6.2 × 14.7 | — | база циліндра рукояті у вежу F | — |
| 7.7 | `49_pin_G` | 1 | Ø6.2 × 19.7 | — | шток циліндра рукояті у п'яту G | Між щоками, крізь розпірні втулки G |
| 7.8 | `47_pin_E` | 1 | Ø7.2 × 30.5 | — | ківш на кінець рукояті | Крізь втулку E, вуха ковша і зовнішні бобишки |
| 7.9 | `53_pin_R` | 1 | Ø7.2 × 20.9 | — | коромисло на накладки кінця рукояті | Крізь втулку R |
| 7.10 | `50_pin_H` | 1 | Ø6.2 × 14.7 | — | база циліндра ковша у вилку H | — |
| 7.11 | `51_pin_J` | 1 | Ø6.2 × 40.1 | — | шток циліндра ковша і тяги на коромислі | Найдовший палець Ø25 разом із Q |
| 7.12 | `52_pin_Q` | 1 | Ø6.2 × 40.1 | — | тяга у вуха ковша | Крізь розпірку Q |

## Позначення

- **Ескіз** — аркуш із контуром і розмірами деталі В МЕТАЛІ. Саме за ним
  упізнаєте пластину, коли на столі лежать три схожі. Аркушів немає у смуг,
  круглих деталей і пальців: їхні розміри цілком описані рядком специфікації.
- **Габарит друку** — виміряний зі STL, у міліметрах надрукованої деталі.
  Розмір у металі (лист 8 мм, труба 120×80×5 тощо) — у `BOM.md` і `parts.tsv`.
- Числа в колонці **Як** — це розміри В МЕТАЛІ, як їх бачить модель
  (отвір Ø66, проміжок 30 мм). На надрукованій деталі вони вп'ятеро менші:
  Ø66 → 13.2 мм, проміжок 30 → 6 мм. Так зроблено навмисно — за цими числами
  деталь упізнається на кресленнях і в BOM.
- **К-сть** — скільки штук цього файлу в наборі; дзеркальні пари друкуються
  з одного файлу, тож ліва й права деталь однакові.
- Кроки 1–5 — вузли, їх можна складати в будь-якому порядку між собою.
  Крок 6 (циліндри) і 7 (пальці) — останні.

---
<sub>Ihor Ivaniuk · @IBITLAB</sub>

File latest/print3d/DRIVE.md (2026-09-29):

# Привід циліндрів гвинтом M5

> Згенеровано `print3d-parts/model_drive.py` (крок `make.sh`) з виміряних STL набору. Руками не правити: припущення — сталі на початку скрипту.

Якщо циліндр моделі — гвинт **M5×0.8** (шток) і гайка, яку крутить моторедуктор, то за один оберт гайки шток проходить 0.8 мм. Щоб модель рухалась **як машина**, кожен циліндр має пройти свій хід за той самий час, що й справжній від насоса (11 л/хв, НШ-10 через редукцію 3 — `docs/TECHNICAL.md`, розділ 5). Тобто шток моделі в 5 разів повільніший, а швидкість гайки n = v / 0.8. Висування повільніше за втягування: при висуванні олія заповнює всю площу поршня, а при втягуванні лише кільце навколо штока.

| Циліндр | Рух | Шток машини, мм/с | Час ходу, с | Шток моделі, мм/с | Гайка M5×0.8, об/хв | Гайка M5×0.8, об/с | Обертів на хід |
|---|---|---:|---:|---:|---:|---:|---:|
| Стріла | висування | 58.8 | 8.5 | 11.8 | 882 | 14.7 | 125 |
| Стріла | втягування | 98.5 | 5.1 | 19.7 | 1478 | 24.6 | 125 |
| Рукоять | висування | 93.4 | 4.3 | 18.7 | 1401 | 23.3 | 100 |
| Рукоять | втягування | 124.5 | 3.2 | 24.9 | 1867 | 31.1 | 100 |
| Ківш | висування | 93.4 | 3.2 | 18.7 | 1401 | 23.3 | 75 |
| Ківш | втягування | 124.5 | 2.4 | 24.9 | 1867 | 31.1 | 75 |

Це найбільші швидкості: коли розподільник пускає весь потік в один циліндр. Якщо рухаються два одразу, потік ділиться, і в машини, і в моделі.

### Маса рухомих частин

Об'єм — із самих STL набору, густина PLA 1.24 г/см³, заповнення 100 % (стінки набору тонкі й друкуються майже суцільними, тож це верхня межа). Пісок — повний ківш «з шапкою»: 21.3 л у машині = 170 см³ у моделі.

| Що | Маса, г |
|---|---:|
| Стріла | 61 |
| Рукоять | 38 |
| Ківш | 33 |
| Важільна система | 11 |
| Гідроциліндри | 54 |
| Втулки й бобишки | 9 |
| Пальці | 6 |
| Моторедуктори на циліндрах рукояті й ковша (оцінка), 2 × 15 | 30 |
| **Разом рухоме** | **241** |
| Пісок у ковші, ρ = 1.6 г/см³ | 273 |
| 24 г колони й пальців A, C не рахуються: вони не рухаються | — |

### Навантаження і моторедуктор

Сила на кожному циліндрі — найгірша з 21³ поз у межах ходів (віртуальна робота: скільки грамів піднімається на мм ходу). Центри ваги деталей поставлено в їхні шарніри чи на середину ланки, ковша й піску — у центр профілю з `tools/bucket.py`. Момент на гайці — різьба M5×0.8 (тертя 0.2) плюс торець гайки об опору (тертя 0.2). M5 самогальмівний: опускати вантаж теж треба крутити, момент менший, але не нуль. Потужність — на гайці, при обертах із таблиці вище. **Паспорт** — що має бути в моторедуктора: номінальний (не пусковий) момент із запасом ×2 на тертя друкованих шарнірів, перекіс і просідання напруги; оберти під навантаженням не менші за потрібні (холостий хід ≈ на 20–25 % вищий).

| Циліндр | Рух | Вага проти руху, Н (порожній / з піском) | Момент на гайці, Н·мм (порожній / з піском) | Потужність на гайці, Вт (порожній / з піском) | Паспорт: момент ≥, г·см (порожній / з піском) | Паспорт: оберти ≥, об/хв |
|---|---|---:|---:|---:|---:|---:|
| Стріла | висування | 11.9 / 33.9 | 15.5 / 44.2 | 1.4 / 4.1 | 315 / 902 | 882 |
| Стріла | втягування | 0.0 / 0.0 | 12.3 / 35.1 | 1.9 / 5.4 | 250 / 716 | 1478 |
| Рукоять | висування | 5.0 / 26.0 | 6.5 / 33.9 | 1.0 / 5.0 | 133 / 691 | 1401 |
| Рукоять | втягування | 5.0 / 25.4 | 6.5 / 33.0 | 1.3 / 6.5 | 132 / 674 | 1867 |
| Ківш | висування | 2.5 / 22.6 | 3.2 / 29.4 | 0.5 / 4.3 | 66 / 600 | 1401 |
| Ківш | втягування | 1.1 / 9.8 | 2.6 / 23.3 | 0.5 / 4.6 | 52 / 476 | 1867 |

«Вага проти руху» — найбільша сила, яку гайка долає, піднімаючи; у позах, де вага сама тягне в бік руху, гайка її гальмує, і момент рахується й для цього випадку — у таблиці більший із двох. Найважче стрілі: вона тримає все. Пісок важить більше за саму модель: якщо копати не треба, підбирай за «порожнім». Маса приводу взята під N20 (15 г); важчий мотор (25GA ≈ 70–100 г) сам додає навантаження стрілі — зміни `DRIVE_G` і перерахуй. Упорний підшипник під гайкою (F5-10M) прибирає тертя торця — момент падає майже вдвічі. Припущення (витрата, тертя, заповнення, маса приводу, запас) — сталі на початку `print3d-parts/model_drive.py`; після зміни — `python3 print3d-parts/model_drive.py`.

### Моторедуктор N20 (12GAN20, 12 В)

Число після дефіса в назві 12GAN20-**X** — передатне число редуктора: -50 = 50:1. Мотор у більшості 12-вольтових варіантів той самий (≈ 20 000 об/хв до редуктора), тож більше X — повільніший вал і більший момент. Паспортним моментам цієї серії вірити не можна: за ними механічна потужність виходить більшою за електричну (ККД понад 100 %). Тому момент зупинки перераховано зі струму: T = η·U·(I_зуп − I_хх)/ω₀, ККД редуктора — оцінка 0.45–0.70. Найбільша потужність мотора — на половині моменту зупинки й половині обертів.

| Мотор | Холостий хід, об/хв | Струм зупинки, А | Момент зупинки за даташитом, Н·мм | Момент зупинки зі струму, Н·мм | Найбільша потужність, Вт |
|---|---:|---:|---:|---:|---:|
| 12GAN20-10, 4000 об/хв | 4000 | 0.60 | 59 | 8.8 | 0.92 |
| 12GAN20-10, 2000 об/хв | 2000 | 0.35 | 98 | 13.2 | 0.69 |
| 12GAN20-20, 1000 об/хв | 1000 | 0.60 | 235 | 30.5 | 0.80 |
| 12GAN20-30, 800 об/хв | 800 | 0.40 | 294 | 24.9 | 0.52 |
| 12GAN20-30, 600 об/хв | 600 | 0.20 | 314 | 19.5 | 0.31 |
| 12GAN20-50, 400 об/хв | 400 | 0.30 | 392 | 32.7 | 0.34 |
| 12GAN20-100, 300 об/хв | 300 | 0.30 | 392 | 52.5 | 0.41 |
| 12GAN20-200, 200 об/хв ¹ | 200 | 1.00 | 686 | 280.7 | 1.47 |
| 12GAN20-298, 130 об/хв ¹ | 130 | 1.00 | 883 | 353.0 | 1.20 |
| 12GAN20-298, 100 об/хв ¹ | 100 | 1.00 | 1569 | 495.0 | 1.30 |
| 12GAN20-298, 60 об/хв ¹ | 60 | 1.00 | 1569 | 825.1 | 1.30 |

¹ Струм зупинки рівно 1.00 А в кількох рядках поспіль схожий на заглушку в даташиті — момент і потужність цих рядків, найімовірніше, завищені.

Нижче — вал мотора прямо на гайці (1:1). Під навантаженням оберти падають лінійно: n = n₀·(1 − T/T_зуп). У клітинці — час висування / втягування моделі і яку частку моменту зупинки бере найважчий із двох рухів; ⚠ — понад 50 %: мотор гріється, для постійної роботи не годиться. Упорний підшипник F5-10M під гайкою прибирає тертя її торця.

**Порожня модель:**

| Циліндр | Машина: висування / втягування, с | 12GAN20-10, 2000 об/хв | 12GAN20-20, 1000 об/хв | 12GAN20-30, 800 об/хв | 12GAN20-50, 400 об/хв |
|---|---:|---:|---:|---:|---:|
| Стріла | 8.5 / 5.1 | стоїть | 15 / 13 с · 51 % ⚠ | 25 / 18 с · 62 % ⚠ | 36 / 30 с · 47 % |
| Рукоять | 4.3 / 3.2 | 6 / 6 с · 49 % | 8 / 8 с · 21 % | 10 / 10 с · 26 % | 19 / 19 с · 20 % |
| Ківш | 3.2 / 2.4 | 3 / 3 с · 24 % | 5 / 5 с · 11 % | 6 / 6 с · 13 % | 12 / 12 с · 10 % |
| Стріла, упорний підшипник | 8.5 / 5.1 | 9 / 6 с · 59 % ⚠ | 10 / 9 с · 25 % | 14 / 11 с · 31 % | 25 / 22 с · 24 % |
| Рукоять, упорний підшипник | 4.3 / 3.2 | 4 / 4 с · 25 % | 7 / 7 с · 11 % | 9 / 9 с · 13 % | 17 / 17 с · 10 % |
| Ківш, упорний підшипник | 3.2 / 2.4 | 3 / 2 с · 12 % | 5 / 5 с · 5 % | 6 / 6 с · 7 % | 12 / 12 с · 5 % |

**З повним ковшем піску:**

| Циліндр | Машина: висування / втягування, с | 12GAN20-10, 2000 об/хв | 12GAN20-20, 1000 об/хв | 12GAN20-30, 800 об/хв | 12GAN20-50, 400 об/хв |
|---|---:|---:|---:|---:|---:|
| Стріла | 8.5 / 5.1 | стоїть | стоїть | стоїть | стоїть |
| Рукоять | 4.3 / 3.2 | стоїть | стоїть | стоїть | стоїть |
| Ківш | 3.2 / 2.4 | стоїть | 121 / 19 с · 96 % ⚠ | стоїть | 113 / 39 с · 90 % ⚠ |
| Стріла, упорний підшипник | 8.5 / 5.1 | стоїть | 27 / 13 с · 73 % ⚠ | 85 / 20 с · 89 % ⚠ | 58 / 31 с · 68 % ⚠ |
| Рукоять, упорний підшипник | 4.3 / 3.2 | стоїть | 14 / 13 с · 56 % ⚠ | 24 / 22 с · 68 % ⚠ | 31 / 30 с · 52 % ⚠ |
| Ківш, упорний підшипник | 3.2 / 2.4 | стоїть | 9 / 6 с · 48 % | 14 / 9 с · 59 % ⚠ | 21 / 15 с · 45 % |

- **Порожня модель, без підшипника:** один тип на всі три — 12GAN20-50, 400 об/хв; найшвидший із них (12GAN20-50, 400 об/хв) повільніший за машину в 3.9–5.9 раза. Найшвидший придатний окремо: стріла — 12GAN20-50, 400 об/хв, рукоять — 12GAN20-10, 2000 об/хв, ківш — 12GAN20-10, 2000 об/хв.
- **Порожня модель, з упорним підшипником:** один тип на всі три — 12GAN20-20, 1000 об/хв, 12GAN20-30, 800 об/хв, 12GAN20-50, 400 об/хв; найшвидший із них (12GAN20-20, 1000 об/хв) повільніший за машину в 1.2–2.1 раза. Найшвидший придатний окремо: стріла — 12GAN20-20, 1000 об/хв, рукоять — 12GAN20-10, 2000 об/хв, ківш — 12GAN20-10, 2000 об/хв.
- **З піском:** стріла, рукоять — не тягне жоден N20 навіть з упорним підшипником; тут потрібен мотор класу 370 або 25GA (важчий — зміни `DRIVE_G`).

Це оцінка: перевір на своєму моторі — важок на важелі до вала або струм під навантаженням проти таблиці.

---
<sub>Ihor Ivaniuk · @IBITLAB</sub>

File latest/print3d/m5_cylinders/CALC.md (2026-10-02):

# Циліндри M5 — розрахунок

> Згенеровано `print3d-parts/m5_cylinders/calc.py` (крок `make.sh`) — руками не правити. Як влаштовано й навіщо — `print3d-parts/m5_cylinders/README.md`.

## Довжини (друковані мм, 1:5)

Зведена довжина й хід — ті самі, що в моделі. Упори — поршень (сталева гайка) об дно кришки (зведений) і об задній торець голови (розкритий); шийка вушка штока голови не торкається.

| Циліндр | Зведений | Хід | Розкритий | Гільза: Ø зовн. / канал під ключ | Дно кришки | Голова від | Запас на ніс | Шпилька M5 |
|---|---:|---:|---:|---|---:|---:|---:|---:|
| Стріла | 140 | 100 | 240 | 15.2 / 8.4 | 10.2 | 114.2 | 0.1 | 126 |
| Рукоять | 120 | 80 | 200 | 12.0 / 8.4 | 10.2 | 94.2 | 0.1 | 106 |
| Ківш | 102 | 60 | 162 | 12.0 / 8.4 | 10.2 | 74.2 | 2.1 | 88 |

«Дно кришки» й «голова від» — від осі пальця бази. Голова займає 16.2 мм; що лишилось («запас на ніс») — напрямна шпильки попереду голови.

## Маса циліндрів

| Циліндр | Друковане: корпус, г | Друковане: шток, г | Шпилька, г | Разом з мотором, г |
|---|---:|---:|---:|---:|
| Стріла | 27.4 | 0.7 | 20.3 | 66.8 |
| Рукоять | 17.0 | 0.6 | 17.3 | 53.3 |
| Ківш | 15.9 | 0.6 | 14.5 | 49.4 |

Друковане — з STL циліндрів, PLA 1.24 г/см³, 100 %. Мотор 10 г і гайка з підшипником сидять у голові; сталь шпильки важить приблизно як уся друкована гільза. Решта машини — з STL набору.

## Вибраний мотор

**12GAN20-298, 60 об/хв**, шестерні стріла 27/27, рукоять 27/27, ківш 27/27, міжосьова 16.20 мм. Час ходу моделі (висування / втягування) і частка моменту зупинки мотора:

| Циліндр | Машина, с | Модель порожня, с | Модель з піском, с | Повільніше за машину |
|---|---:|---:|---:|---:|
| Стріла | 8.5 / 5.1 | 127 / 126 · 1.4 % | 129 / 128 · 3.3 % | ×25 |
| Рукоять | 4.3 / 3.2 | 101 / 101 · 0.5 % | 102 / 102 · 2.4 % | ×31 |
| Ківш | 3.2 / 2.4 | 75 / 75 · 0.2 % | 77 / 76 · 2.0 % | ×31 |

Сила ваги на циліндрах, Н (порожня / з піском, штовхає / тягне): стріла 16.0/0.0 · 38.0/0.0; рукоять 5.9/5.9 · 26.9/26.2; ківш 2.2/1.3 · 22.3/10.0.

**Упори.** Номінальний момент з даташиту (196 Н·мм) дає на шпильці ≈ 270 Н, момент зупинки (825–1569 Н·мм) — ≈ 1137 Н (струм зупинки в даташиті — «заглушка» 1.00 А). Вага ж — не більше 38 Н. Друковані упори (698ZZ осьово тримає ≈ 400 Н) розраховані на вагу, а не на мотор: зупиняють датчики кінцевиків, драйвер обмежує струм.

## Що дали б інші N20

Шестерня гайки z = 27 (менша не вміщає гайку й магніти), модуль 0.6. Мотор не ближче 0.6 мм до гільзи й не далі 18 мм від осі, тож прискорити гайку шестернями майже нікуди (i ≥ 0.79) — швидкість задає сам мотор. ККД пари 0.9. Кожен мотор — з найкомпактнішою парою, не повільнішою за найшвидшу більш ніж на 10 %, і лише без перегріву (≤ 50 % моменту зупинки) на порожній моделі.

| Мотор | Стріла | Рукоять | Ківш | Повільніше за машину |
|---|---|---|---|---:|
| 12GAN20-20, 1000 об/хв | 27/29: 11.8 / 9.2 с · 41 % | 27/30: 6.4 / 6.4 с · 16 % | 27/30: 4.3 / 4.2 с · 6 % | ×2.0 |
| 12GAN20-30, 800 об/хв | 27/25: 17.8 / 13.6 с · 43 % | 27/30: 8.3 / 8.3 с · 19 % | 27/30: 5.5 / 5.3 с · 7 % | ×2.7 |
| 12GAN20-30, 600 об/хв | 27/19: 30.6 / 23.6 с · 42 % | 27/29: 12.2 / 12.2 с · 24 % | 27/30: 7.4 / 7.1 с · 9 % | ×4.6 |
| 12GAN20-50, 400 об/хв | 27/29: 28.2 / 22.5 с · 38 % | 27/30: 15.8 / 15.8 с · 15 % | 27/30: 10.7 / 10.5 с · 6 % | ×4.9 |
| 12GAN20-100, 300 об/хв | 27/30: 29.8 / 26.3 с · 25 % | 27/30: 19.8 / 19.8 с · 9 % | 27/30: 14.0 / 13.8 с · 3 % | ×6.2 |
| 12GAN20-298, 60 об/хв ← вибрано | 27/30: 114.3 / 113.5 с · 2 % | 27/30: 90.5 / 90.5 с · 1 % | 27/30: 67.6 / 67.6 с · 0 % | ×28.2 |

Машина: стріла 8.5 / 5.1 с, рукоять 4.3 / 3.2 с, ківш 3.2 / 2.4 с (висування / втягування, весь потік насоса в один циліндр).

---
<sub>Ihor Ivaniuk · @IBITLAB</sub>

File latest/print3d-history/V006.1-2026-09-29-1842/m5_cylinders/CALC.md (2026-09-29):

# Циліндри M5 — розрахунок

> Згенеровано `print3d-parts/m5_cylinders/calc.py` (крок `make.sh`) — руками не правити. Як влаштовано й навіщо — `print3d-parts/m5_cylinders/README.md`.

## Довжини (друковані мм, 1:5)

Зведена довжина й хід — ті самі, що в моделі. Упори — поршень об дно кришки (зведений) і об задній торець голови (розкритий); шийка вушка штока голови не торкається.

| Циліндр | Зведений | Хід | Розкритий | Гільза Ø зовн. / внутр. | Дно кришки | Голова від | Запас на ніс | Шпилька M5 |
|---|---:|---:|---:|---|---:|---:|---:|---:|
| Стріла | 140 | 100 | 240 | 15.2 / 11.0 | 10.2 | 116.2 | 0.8 | 126 |
| Рукоять | 120 | 80 | 200 | 12.0 / 9.0 | 10.2 | 96.2 | 0.8 | 106 |
| Ківш | 102 | 60 | 162 | 12.0 / 9.0 | 10.2 | 76.2 | 2.8 | 88 |

«Дно кришки» й «голова від» — від осі пальця бази. Голова займає 13.0 мм; що лишилось («запас на ніс») — напрямна шпильки попереду голови.

## Маса циліндрів

| Циліндр | Друковане: корпус, г | Друковане: шток, г | Шпилька, г | Разом з мотором, г |
|---|---:|---:|---:|---:|
| Стріла | 22.3 | 1.2 | 19.4 | 54.9 |
| Рукоять | 15.9 | 0.9 | 16.4 | 45.2 |
| Ківш | 14.7 | 0.9 | 13.6 | 41.2 |

Друковане — з STL циліндрів, PLA 1.24 г/см³, 100 %. Мотор 10 г і гайка з підшипником сидять у голові; сталь шпильки важить приблизно як уся друкована гільза. Решта машини — з STL набору.

## Вибраний мотор

**12GAN20-298, 60 об/хв**, шестерні стріла 27/27, рукоять 27/27, ківш 27/27, міжосьова 16.20 мм. Час ходу моделі (висування / втягування) і частка моменту зупинки мотора:

| Циліндр | Машина, с | Модель порожня, с | Модель з піском, с | Повільніше за машину |
|---|---:|---:|---:|---:|
| Стріла | 8.5 / 5.1 | 127 / 126 · 1.3 % | 129 / 127 · 3.2 % | ×25 |
| Рукоять | 4.3 / 3.2 | 100 / 100 · 0.5 % | 102 / 102 · 2.3 % | ×31 |
| Ківш | 3.2 / 2.4 | 75 / 75 · 0.2 % | 77 / 76 · 2.0 % | ×31 |

Сила ваги на циліндрах, Н (порожня / з піском, штовхає / тягне): стріла 14.7/0.0 · 36.7/0.0; рукоять 5.6/5.6 · 26.6/26.0; ківш 2.3/1.2 · 22.3/9.9.

**Упори.** Номінальний момент з даташиту (196 Н·мм) дає на шпильці ≈ 270 Н, момент зупинки (825–1569 Н·мм) — ≈ 1137 Н (струм зупинки в даташиті — «заглушка» 1.00 А). Вага ж — не більше 37 Н. Друковані упори й MR128 (осьово ≈ 150 Н) розраховані на вагу, а не на мотор: зупиняють датчики кінцевиків, драйвер обмежує струм.

## Що дали б інші N20

Шестерня гайки z = 27 (менша не вміщає гайку й магніти), модуль 0.6. Мотор не ближче 0.6 мм до гільзи й не далі 18 мм від осі, тож прискорити гайку шестернями майже нікуди (i ≥ 0.79) — швидкість задає сам мотор. ККД пари 0.9. Кожен мотор — з найкомпактнішою парою, не повільнішою за найшвидшу більш ніж на 10 %, і лише без перегріву (≤ 50 % моменту зупинки) на порожній моделі.

| Мотор | Стріла | Рукоять | Ківш | Повільніше за машину |
|---|---|---|---|---:|
| 12GAN20-20, 1000 об/хв | 27/29: 11.2 / 9.0 с · 37 % | 27/30: 6.3 / 6.3 с · 15 % | 27/30: 4.3 / 4.2 с · 6 % | ×2.0 |
| 12GAN20-30, 800 об/хв | 27/27: 16.4 / 12.5 с · 43 % | 27/30: 8.3 / 8.2 с · 18 % | 27/30: 5.5 / 5.3 с · 7 % | ×2.6 |
| 12GAN20-30, 600 об/хв | 27/21: 28.0 / 21.5 с · 43 % | 27/29: 12.0 / 12.0 с · 23 % | 27/30: 7.4 / 7.1 с · 9 % | ×4.2 |
| 12GAN20-50, 400 об/хв | 27/29: 26.9 / 22.0 с · 35 % | 27/30: 15.7 / 15.7 с · 14 % | 27/30: 10.7 / 10.5 с · 6 % | ×4.9 |
| 12GAN20-100, 300 об/хв | 27/30: 29.1 / 25.9 с · 23 % | 27/30: 19.7 / 19.7 с · 9 % | 27/30: 14.0 / 13.8 с · 3 % | ×6.1 |
| 12GAN20-298, 60 об/хв ← вибрано | 27/30: 114.1 / 113.5 с · 1 % | 27/30: 90.5 / 90.5 с · 1 % | 27/30: 67.6 / 67.6 с · 0 % | ×28.2 |

Машина: стріла 8.5 / 5.1 с, рукоять 4.3 / 3.2 с, ківш 3.2 / 2.4 с (висування / втягування, весь потік насоса в один циліндр).

---
<sub>Ihor Ivaniuk · @IBITLAB</sub>

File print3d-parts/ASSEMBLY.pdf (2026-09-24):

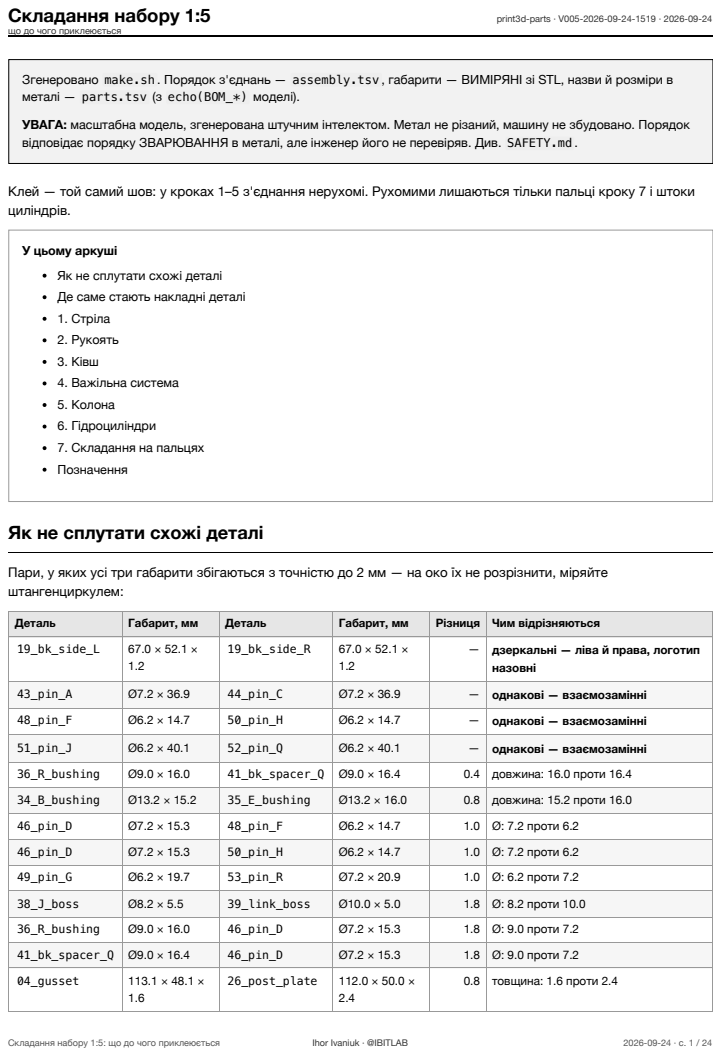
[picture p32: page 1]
Складання набору 1:5; print3d-parts · V005-2026-09-24-1519 · 2026-09-24; Складання набору 1:5: що до чого приклеюється; Ihor Ivaniuk · @IBITLAB

що до чого приклеюється

Згенеровано make.sh . Порядок з'єднань — assembly.tsv , габарити — ВИМІРЯНІ зі STL, назви й розміри в
металі — parts.tsv (з echo(BOM_*) моделі).
УВАГА: масштабна модель, згенерована штучним інтелектом. Метал не різаний, машину не збудовано. Порядок
відповідає порядку ЗВАРЮВАННЯ в металі, але інженер його не перевіряв. Див. SAFETY.md .

Клей — той самий шов: у кроках 1–5 з'єднання нерухомі. Рухомими лишаються тільки пальці кроку 7 і штоки
циліндрів.

У цьому аркуші
Як не сплутати схожі деталі
Де саме стають накладні деталі
1. Стріла
2. Рукоять
3. Ківш
4. Важільна система
5. Колона
6. Гідроциліндри
7. Складання на пальцях
Позначення

Пари, у яких усі три габарити збігаються з точністю до 2 мм — на око їх не розрізнити, міряйте
штангенциркулем:

Деталь | Габарит, мм | Деталь | Габарит, мм | Різниця | Чим відрізняються

19_bk_side_L | 67.0 × 52.1 × 1.2 | 19_bk_side_R | 67.0 × 52.1 × 1.2 | — | дзеркальні — ліва й права, логотип назовні

43_pin_A | Ø7.2 × 36.9 | 44_pin_C | Ø7.2 × 36.9 | — | однакові — взаємозамінні

48_pin_F | Ø6.2 × 14.7 | 50_pin_H | Ø6.2 × 14.7 | — | однакові — взаємозамінні

51_pin_J | Ø6.2 × 40.1 | 52_pin_Q | Ø6.2 × 40.1 | — | однакові — взаємозамінні

36_R_bushing | Ø9.0 × 16.0 | 41_bk_spacer_Q | Ø9.0 × 16.4 | 0.4 | довжина: 16.0 проти 16.4
34_B_bushing | Ø13.2 × 15.2 | 35_E_bushing | Ø13.2 × 16.0 | 0.8 | довжина: 15.2 проти 16.0

46_pin_D | Ø7.2 × 15.3 | 48_pin_F | Ø6.2 × 14.7 | 1.0 | Ø: 7.2 проти 6.2
46_pin_D | Ø7.2 × 15.3 | 50_pin_H | Ø6.2 × 14.7 | 1.0 | Ø: 7.2 проти 6.2
49_pin_G | Ø6.2 × 19.7 | 53_pin_R | Ø7.2 × 20.9 | 1.0 | Ø: 6.2 проти 7.2

38_J_boss | Ø8.2 × 5.5 | 39_link_boss | Ø10.0 × 5.0 | 1.8 | Ø: 8.2 проти 10.0
36_R_bushing | Ø9.0 × 16.0 | 46_pin_D | Ø7.2 × 15.3 | 1.8 | Ø: 9.0 проти 7.2
41_bk_spacer_Q | Ø9.0 × 16.4 | 46_pin_D | Ø7.2 × 15.3 | 1.8 | Ø: 9.0 проти 7.2

04_gusset | 113.1 × 48.1 × 1.6 | 26_post_plate | 112.0 × 50.0 × 2.4 | 0.8 | товщина: 1.6 проти 2.4

Габарити тут — у позі друку (деталь лежить так, як вийшла з принтера), відсортовані від найбільшого до найменшого, щоб порівняння не залежало від того, яким боком ви взяли деталь.

Складання набору 1:5: що до чого приклеюється | Ihor Ivaniuk · @IBITLAB | 2026-09-24 · с. 2 / 24

## Де саме стають накладні деталі

Більшість деталей упирається в кромку або в отвір — їх не поставиш інакше. Але чотири приварюються ПОСЕРЕД пластини, нічим не впираючись: вежа F, вилка D, вилка H і вуха ковша. На око їх не виставити.

Числа ВИМІРЯНІ зі слідів деталей на базових пластинах — не взяті з коду моделі й не вписані руками. Праворуч та сама відстань на надрукованій деталі. Це ті самі числа, що стоять підписами на кресленні.

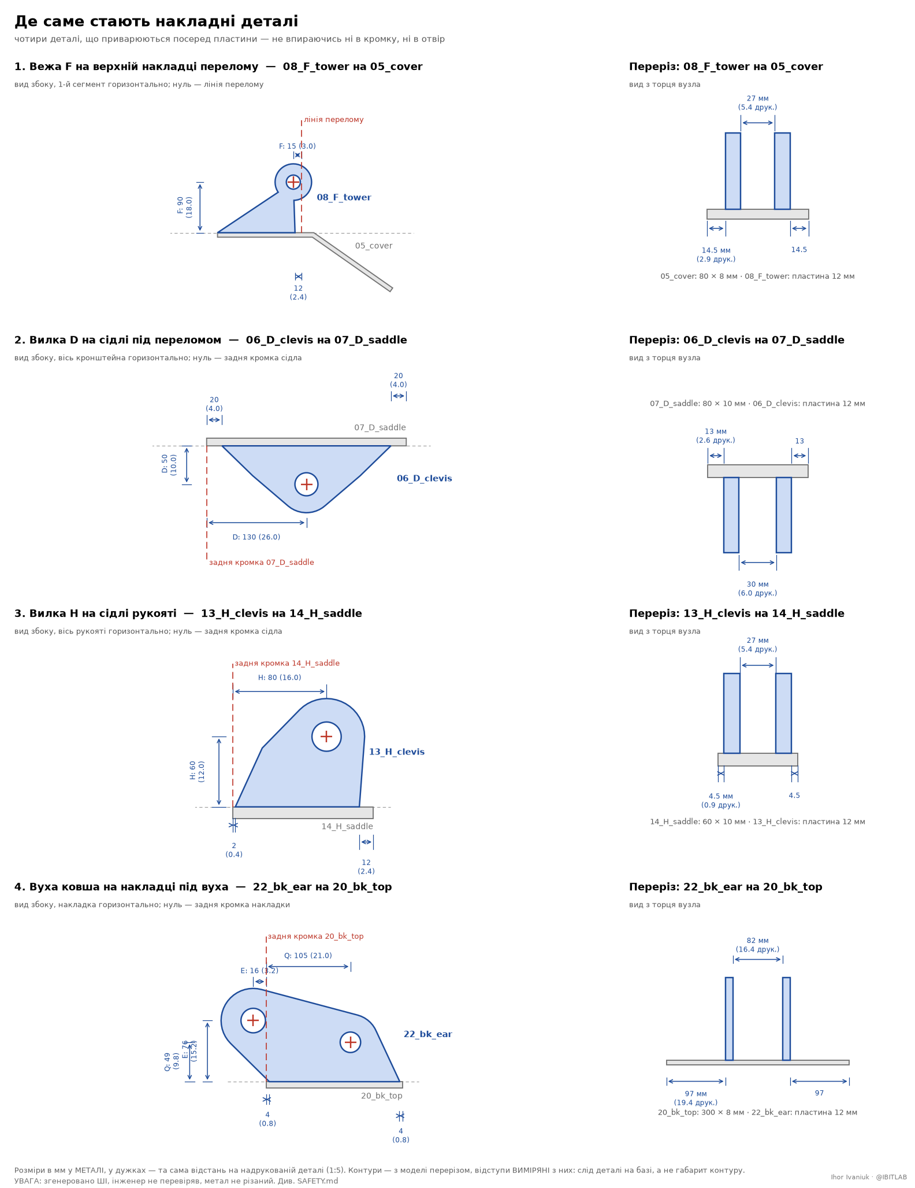
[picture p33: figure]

Складання набору 1:5: що до чого приклеюється | Ihor Ivaniuk · @IBITLAB | 2026-09-24 · с. 3 / 24

08_F_tower на 05_cover

Розмір | У металі, мм | Надруковано, мм
задня кромка деталі від задньої кромки накладки | 0 | 0.00
передня кромка деталі не доходить до лінії перелому на | 12 | 2.40
центр отвору F назад від лінії перелому | 15 | 3.00
центр отвору F від поверхні накладки | 90 | 18.00
проміжок між пластинами пари | 27 | 5.40
від бічної кромки накладки до зовнішньої грані пластини | 14.5 | 2.90

06_D_clevis на 07_D_saddle

Розмір | У металі, мм | Надруковано, мм
відступ від задньої кромки сідла | 20 | 4.00
відступ від передньої кромки сідла | 20 | 4.00
центр отвору D від задньої кромки сідла | 130 | 26.00
центр отвору D від поверхні сідла | 50 | 10.00
проміжок між пластинами пари | 30 | 6.00
від бічної кромки сідла до зовнішньої грані пластини | 13 | 2.60

13_H_clevis на 14_H_saddle

Розмір | У металі, мм | Надруковано, мм
відступ від задньої кромки сідла | 2 | 0.40
відступ від передньої кромки сідла | 12 | 2.40
центр отвору H від задньої кромки сідла | 80 | 16.00
центр отвору H від поверхні сідла | 60 | 12.00
проміжок між пластинами пари | 27 | 5.40
від бічної кромки сідла до зовнішньої грані пластини | 4.5 | 0.90
Складання набору 1:5: що до чого приклеюється | Ihor Ivaniuk · @IBITLAB | 2026-09-24 · с. 4 / 24

22_bk_ear на 20_bk_top

Розмір | У металі, мм | Надруковано, мм
відступ від задньої кромки накладки | 4 | 0.80
відступ від передньої кромки накладки | 4 | 0.80
центр отвору E позаду задньої кромки накладки | 16 | 3.20
центр отвору E від поверхні накладки | 76 | 15.20
центр отвору Q від задньої кромки накладки | 105 | 21.00
центр отвору Q від поверхні накладки | 49 | 9.80
проміжок між пластинами пари | 82 | 16.40
від бічної кромки накладки до зовнішньої грані пластини | 97 | 19.40

Усі чотири — дзеркальні пари й стоять симетрично середній площині вузла, тому «від бічної кромки до зовнішньої грані» однакове з обох боків. Відступи міряються по СЛІДУ деталі на базі: бобишка навколо отвору звисає за основу (у вежі F на 17.5 мм за лінію перелому, у вуха ковша на 56 мм позаду накладки), і за габаритом контуру деталь стала б не на місце.

Складання набору 1:5: що до чого приклеюється | Ihor Ivaniuk · @IBITLAB | 2026-09-24 · с. 5 / 24

## 1. Стріла

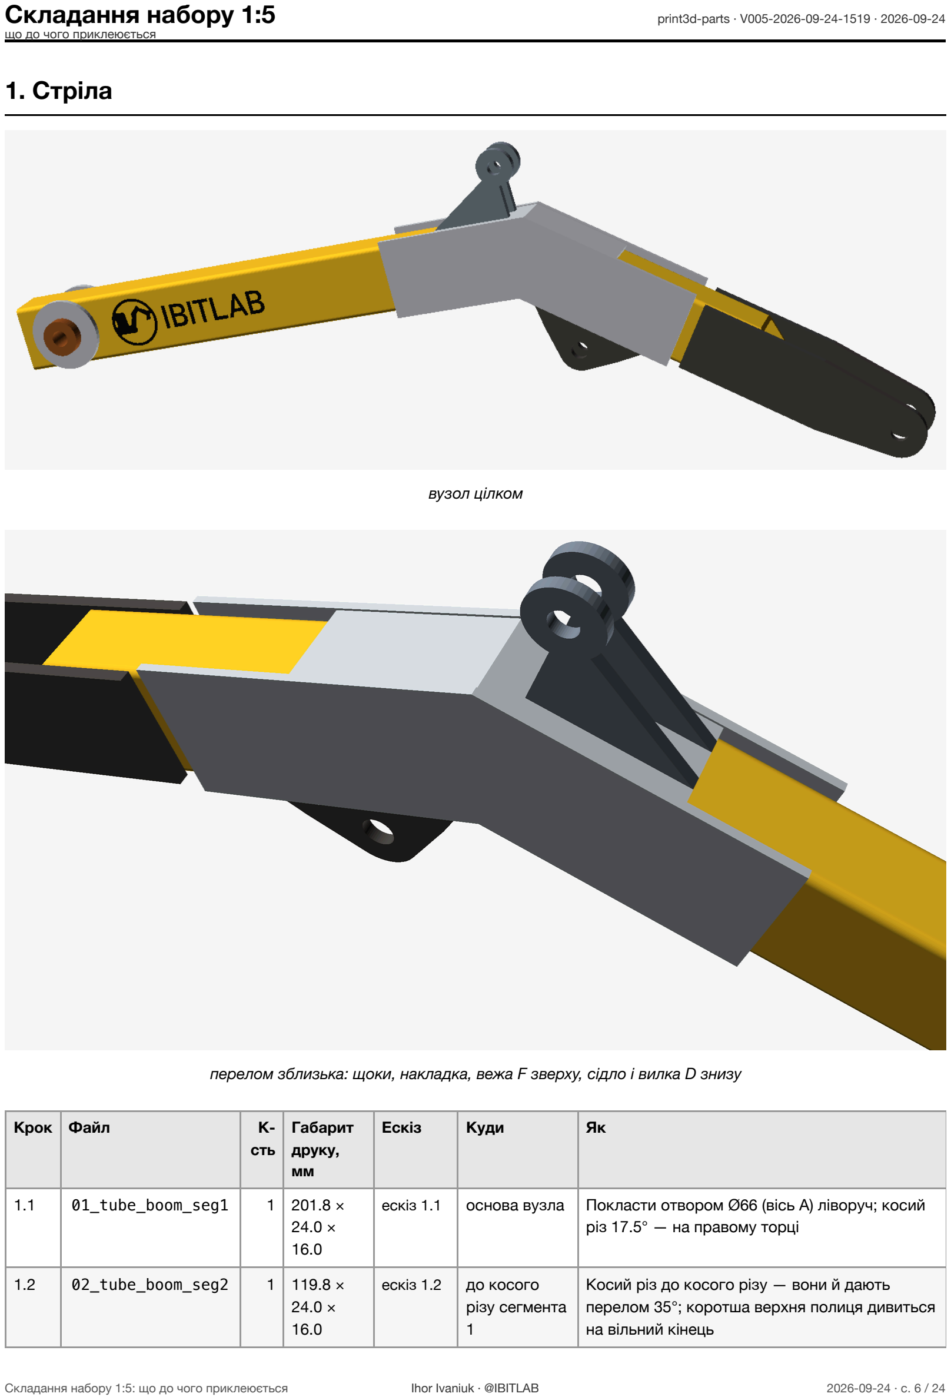
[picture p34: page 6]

вузол цілком

перелом зблизька: щоки, накладка, вежа F зверху, сідло і вилка D знизу

Крок | Файл | К-сть | Габарит друку, мм | Ескіз | Куди | Як
1.1 | 01_tube_boom_seg1 | 1 | 201.8 × 24.0 × 16.0 | ескіз 1.1 | основа вузла | Покласти отвором Ø66 (вісь A) ліворуч; косий різ 17.5° — на правому торці
1.2 | 02_tube_boom_seg2 | 1 | 119.8 × 24.0 × 16.0 | ескіз 1.2 | до косого різу сегмента 1 | Косий різ до косого різу — вони й дають перелом 35°; коротша верхня полиця дивиться на вільний кінець
Складання набору 1:5: що до чого приклеюється | Ihor Ivaniuk · @IBITLAB | 2026-09-24 · с. 6 / 24

Крок | Файл | К-сть | Габарит друку, мм | Ескіз | Куди | Як
1.3 | 04_gusset | 2 | 113.1 × 48.1 × 1.6 | ескіз 1.3 | з обох боків стику труб | Щоки перекривають шов перелому; нижня кромка — урівень із нижньою полицею
1.4 | 05_cover | 1 | 62.4 × 16.0 × 21.0 | — | зверху на перелом, між щоками | Уже зігнута посередині на 35°, лягає одразу на обидві верхні полиці. На неї потім стане вежа F — див. крок 1.8
1.5 | 33_A_bushing | 1 | Ø13.2 × 28.0 | — | в отвір Ø66 сегмента 1 | Наскрізь крізь обидві стінки; виступає з боків порівну — втулка довша за ширину труби
1.6 | 09_A_doubler | 2 | Ø26.0 × 2.0 | ескіз 1.6 | на бічні стінки труби навколо втулки A | По одній накладці з кожного боку, отвором на втулку
1.7 | 10_B_fork | 2 | 84.6 × 46.0 × 2.4 | ескіз 1.7 | на передній торець сегмента 2, з боків | Дві пластини; між ними потім заходить п'ята рукояті
1.8 | 08_F_tower | 2 | 27.8 × 31.0 × 2.4 | ескіз 1.8 | на верхню накладку перелому | Задня кромка — ВРІВЕНЬ із задньою кромкою накладки, передня не доходить до лінії перелому на 12 мм (2.4 друкованих). Уперед не можна: там проходить корпус циліндра. Решта розмірів — розділ «Де саме стають накладні деталі»
1.9 | 07_D_saddle | 1 | 52.0 × 16.0 × 2.0 | — | знизу між щоками перелому | Сідло стає врівень із виступами щік. Під нього потім стане вилка D — див. крок 1.10
1.10 | 06_D_clevis | 2 | 41.4 × 24.2 × 2.4 | ескіз 1.10 | на сідло D | Відступ 20 мм (4.0 друкованих) від кожного торця сідла, отвір — рівно посередині його довжини, проміжок 30 мм. Решта розмірів — розділ «Де саме стають накладні деталі»
Складання набору 1:5: що до чого приклеюється | Ihor Ivaniuk · @IBITLAB | 2026-09-24 · с. 7 / 24

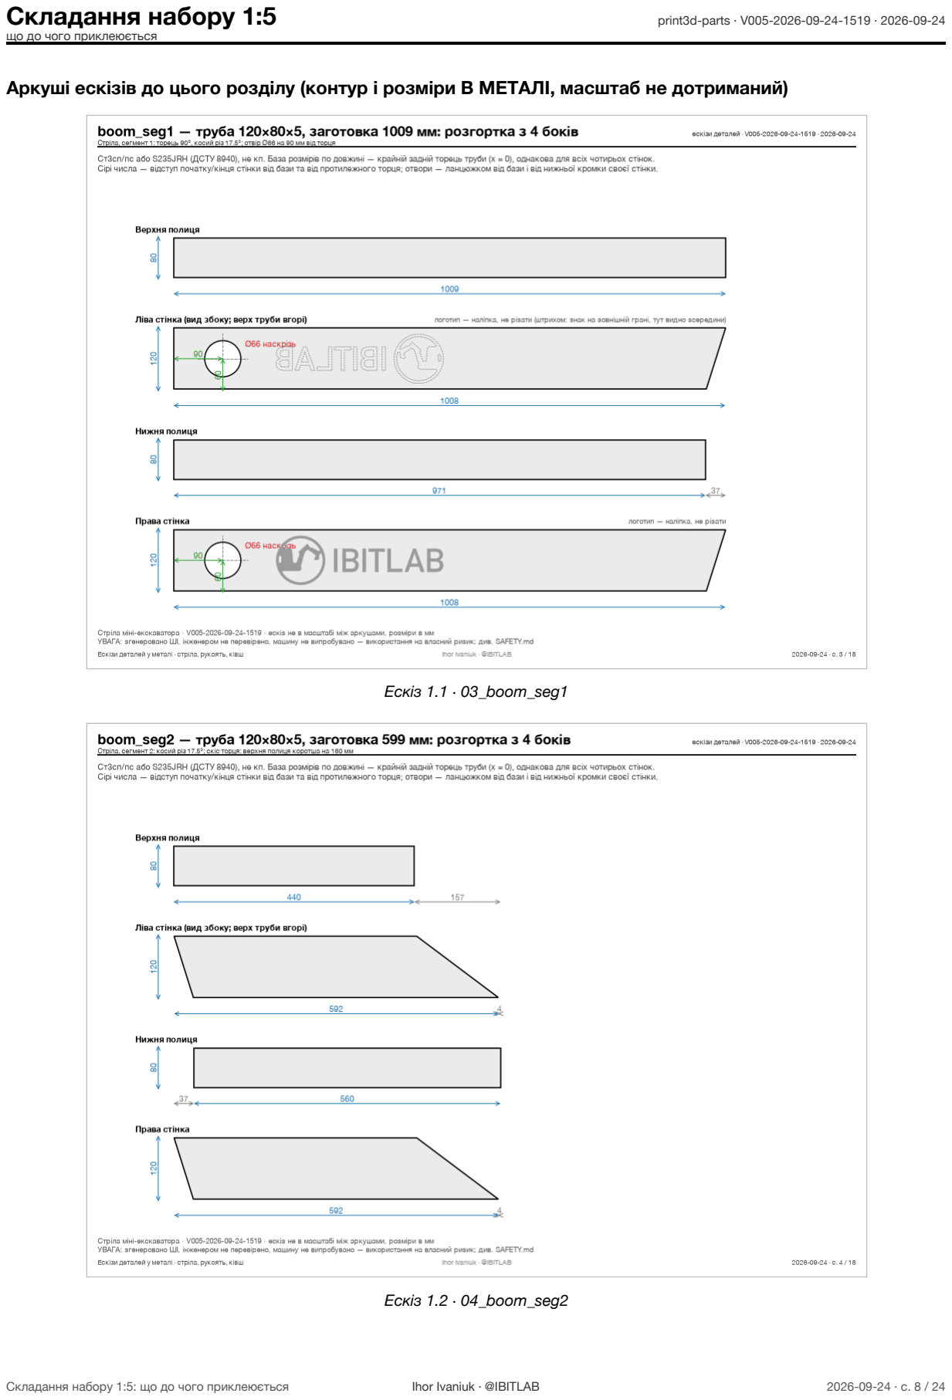
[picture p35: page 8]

### Аркуші ескізів до цього розділу (контур і розміри В МЕТАЛІ, масштаб не дотриманий)

Ескіз 1.1 · 03_boom_seg1

Ескіз 1.2 · 04_boom_seg2

Складання набору 1:5: що до чого приклеюється | Ihor Ivaniuk · @IBITLAB | 2026-09-24 · с. 8 / 24

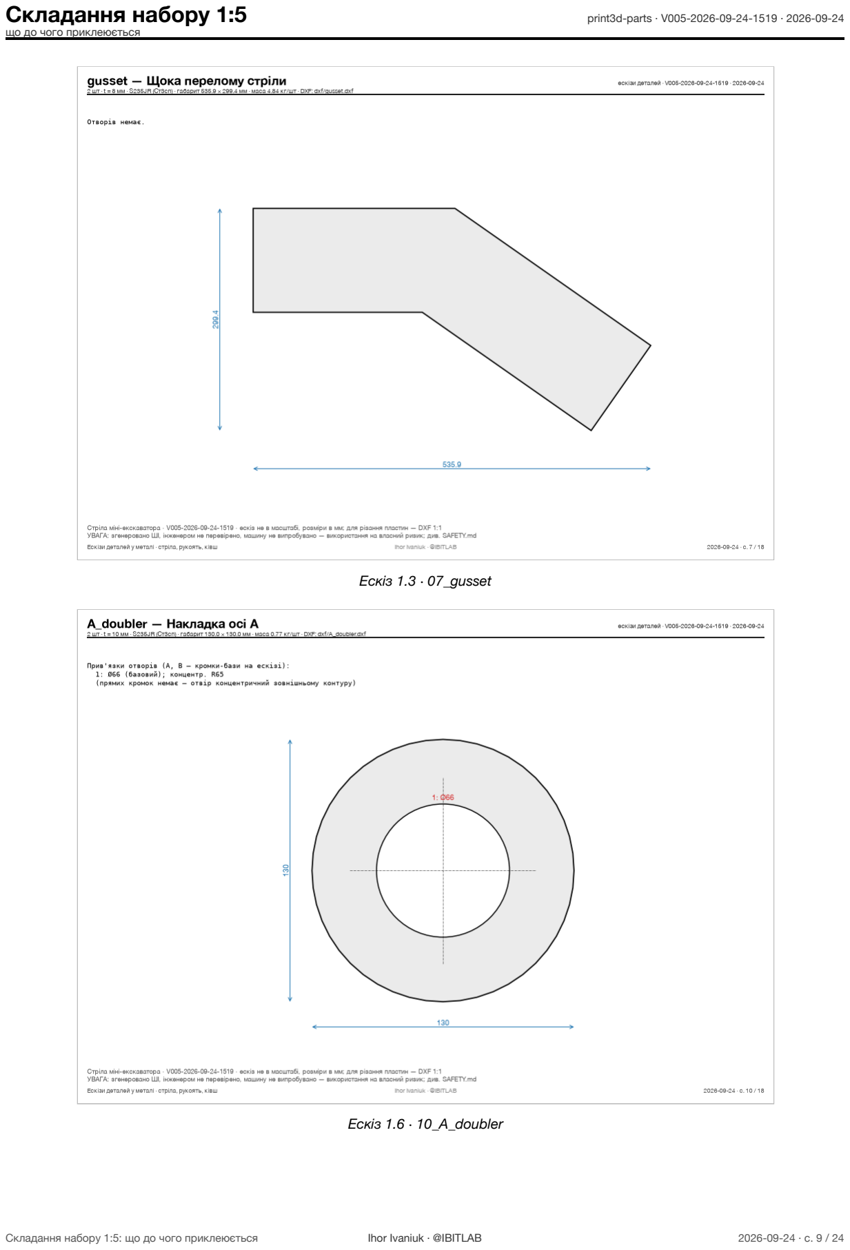
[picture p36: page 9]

Ескіз 1.3 · 07_gusset

Ескіз 1.6 · 10_A_doubler

Складання набору 1:5: що до чого приклеюється | Ihor Ivaniuk · @IBITLAB | 2026-09-24 · с. 9 / 24

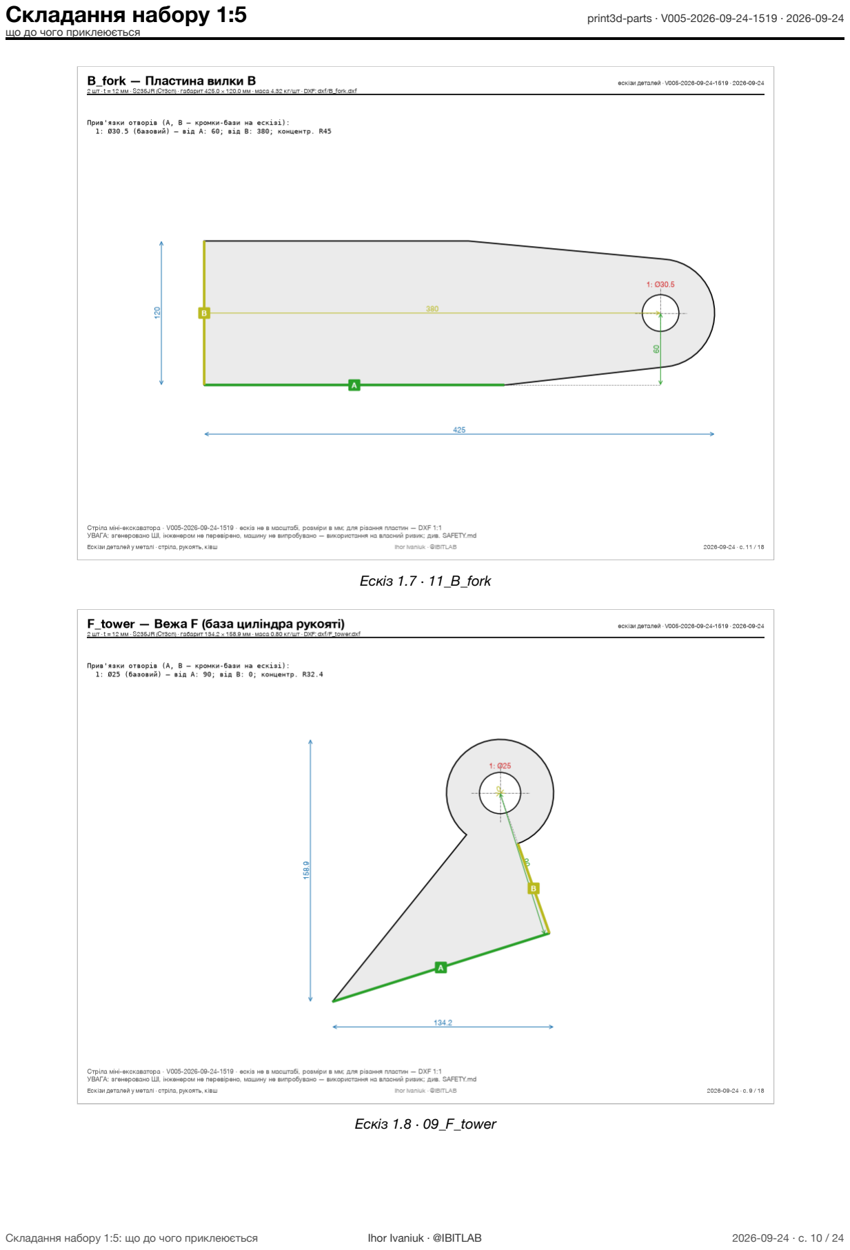
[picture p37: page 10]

Ескіз 1.7 · 11_B_fork

Ескіз 1.8 · 09_F_tower

Складання набору 1:5: що до чого приклеюється | Ihor Ivaniuk · @IBITLAB | 2026-09-24 · с. 10 / 24

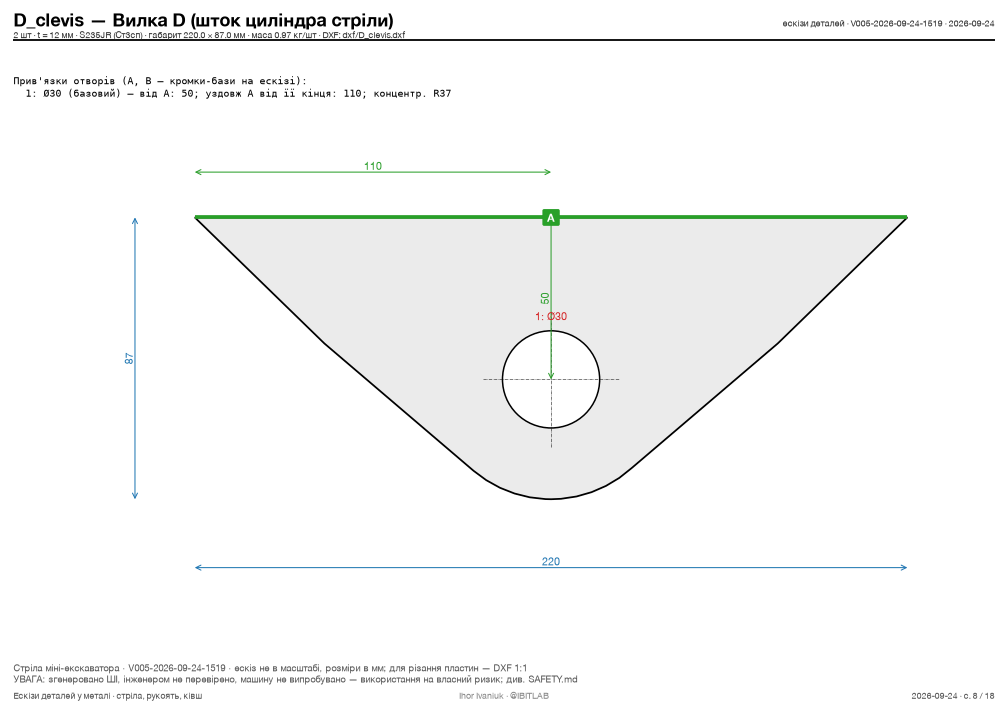
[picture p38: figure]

Ескіз 1.10 · 08_D_clevis

Складання набору 1:5: що до чого приклеюється | Ihor Ivaniuk · @IBITLAB | 2026-09-24 · с. 11 / 24

## 2. Рукоять

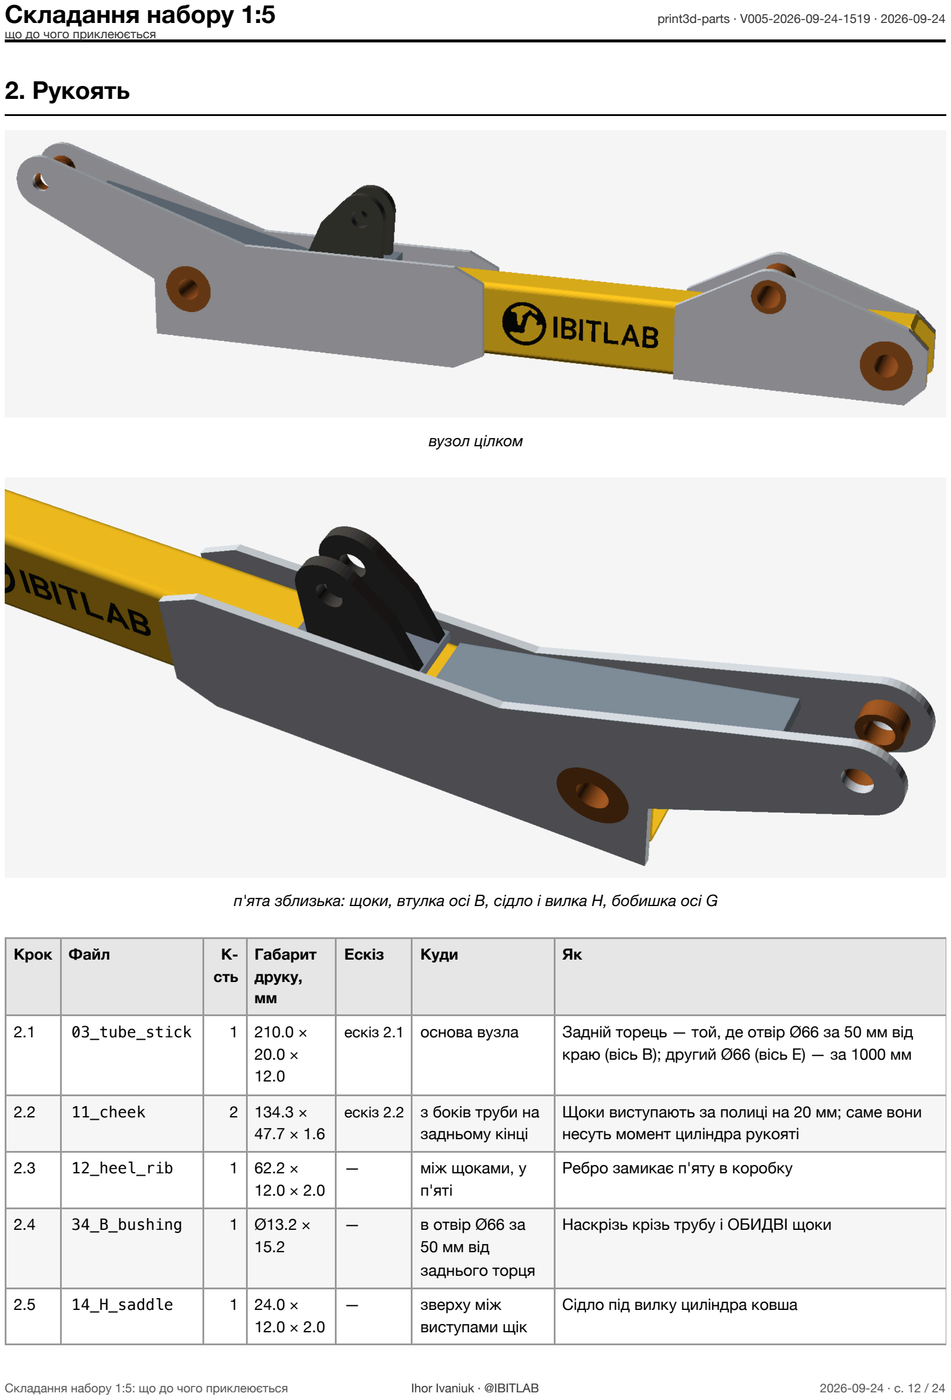
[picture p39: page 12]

вузол цілком

п'ята зблизька: щоки, втулка осі B, сідло і вилка H, бобишка осі G

Крок | Файл | К-сть | Габарит друку, мм | Ескіз | Куди | Як
2.1 | 03_tube_stick | 1 | 210.0 × 20.0 × 12.0 | ескіз 2.1 | основа вузла | Задній торець — той, де отвір Ø66 за 50 мм від краю (вісь B); другий Ø66 (вісь E) — за 1000 мм
2.2 | 11_cheek | 2 | 134.3 × 47.7 × 1.6 | ескіз 2.2 | з боків труби на задньому кінці | Щоки виступають за полиці на 20 мм; саме вони несуть момент циліндра рукояті
2.3 | 12_heel_rib | 1 | 62.2 × 12.0 × 2.0 | — | між щоками, у п'яті | Ребро замикає п'яту в коробку
2.4 | 34_B_bushing | 1 | Ø13.2 × 15.2 | — | в отвір Ø66 за 50 мм від заднього торця | Наскрізь крізь трубу і ОБИДВІ щоки
2.5 | 14_H_saddle | 1 | 24.0 × 12.0 × 2.0 | — | зверху між виступами щік | Сідло під вилку циліндра ковша
Складання набору 1:5: що до чого приклеюється | Ihor Ivaniuk · @IBITLAB | 2026-09-24 · с. 12 / 24

Крок | Файл | К-сть | Габарит друку, мм | Ескіз | Куди | Як
2.6 | 13_H_clevis | 2 | 22.1 × 18.5 × 2.4 | ескіз 2.6 | на сідло H | Стоїть НЕСИМЕТРИЧНО: 2 мм (0.4 друкованих) від задньої кромки сідла, 12 мм (2.4) від передньої — основа тягнеться назад, бо вперед плечей немає, туди лягає корпус циліндра. Решта розмірів — розділ «Де саме стають накладні деталі»
2.7 | 37_G_boss | 2 | Ø7.8 × 3.3 | — | на щоки ззовні, вісь G | Розпірні втулки, по одній на щоку: вони задають проміжок під вушко штока
2.8 | 15_tip_plate | 2 | 64.4 × 31.9 × 2.0 | ескіз 2.8 | на передній кінець труби, з боків | Накладки під осі E і R
2.9 | 35_E_bushing | 1 | Ø13.2 × 16.0 | — | в отвір Ø66 за 1000 мм від заднього торця | Наскрізь крізь трубу і обидві накладки кінця
2.10 | 36_R_bushing | 1 | Ø9.0 × 16.0 | — | між накладками кінця, над верхньою полицею | Вісь коромисла тримається тільки накладками, труби не торкається

### Аркуші ескізів до цього розділу (контур і розміри В МЕТАЛІ, масштаб не дотриманий)

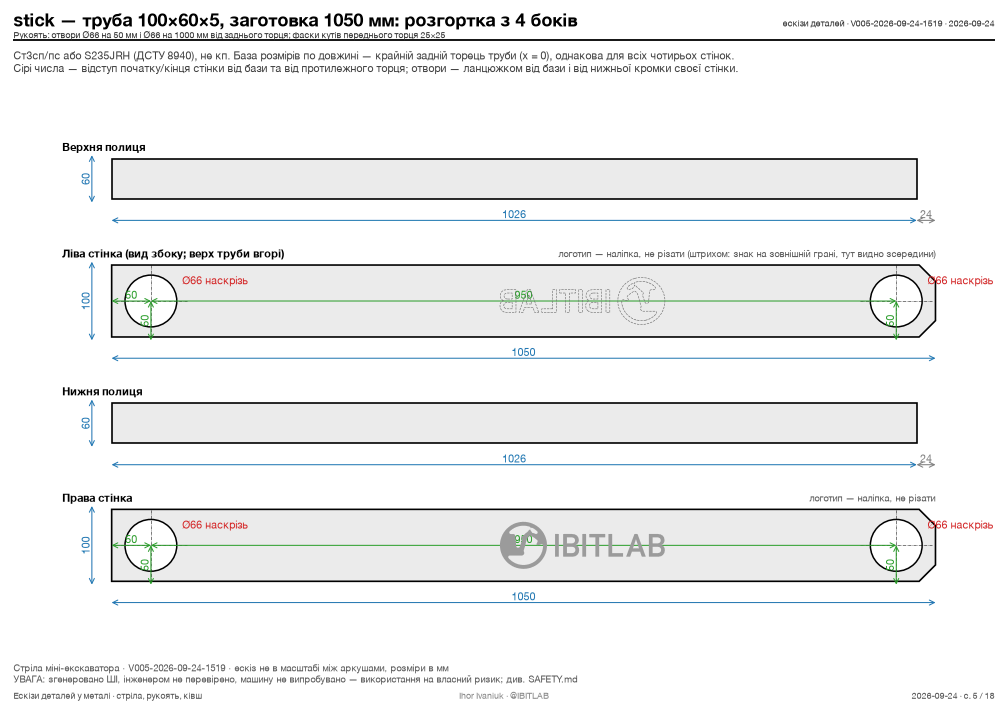
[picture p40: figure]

Ескіз 2.1 · 05_stick

Складання набору 1:5: що до чого приклеюється | Ihor Ivaniuk · @IBITLAB | 2026-09-24 · с. 13 / 24

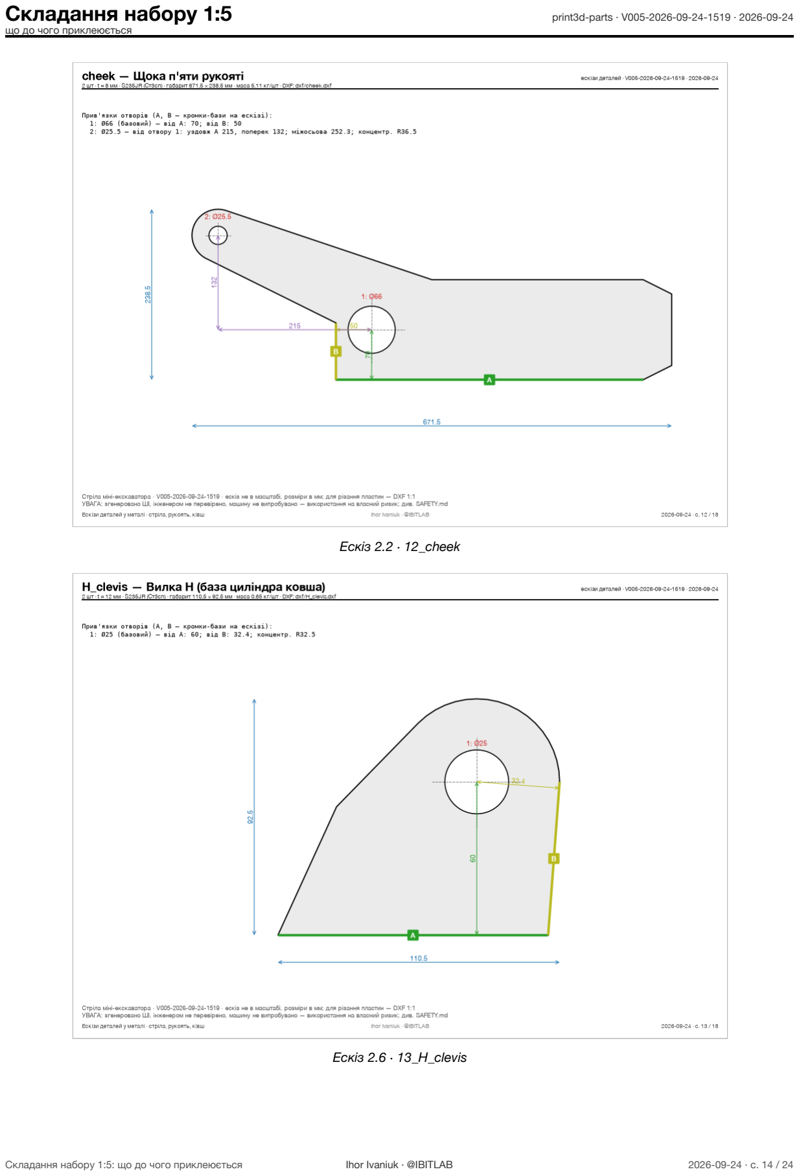
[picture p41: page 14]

Ескіз 2.2 · 12_cheek

Ескіз 2.6 · 13_H_clevis

Складання набору 1:5: що до чого приклеюється | Ihor Ivaniuk · @IBITLAB | 2026-09-24 · с. 14 / 24

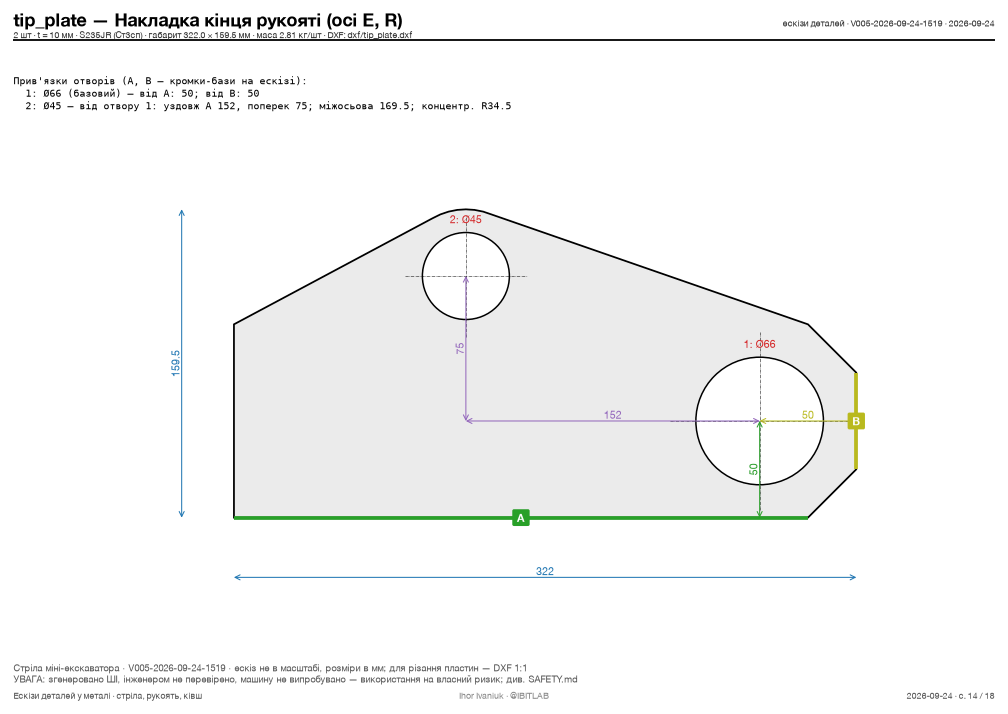
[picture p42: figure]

Ескіз 2.8 · 14_tip_plate

Складання набору 1:5: що до чого приклеюється | Ihor Ivaniuk · @IBITLAB | 2026-09-24 · с. 15 / 24

## 3. Ківш

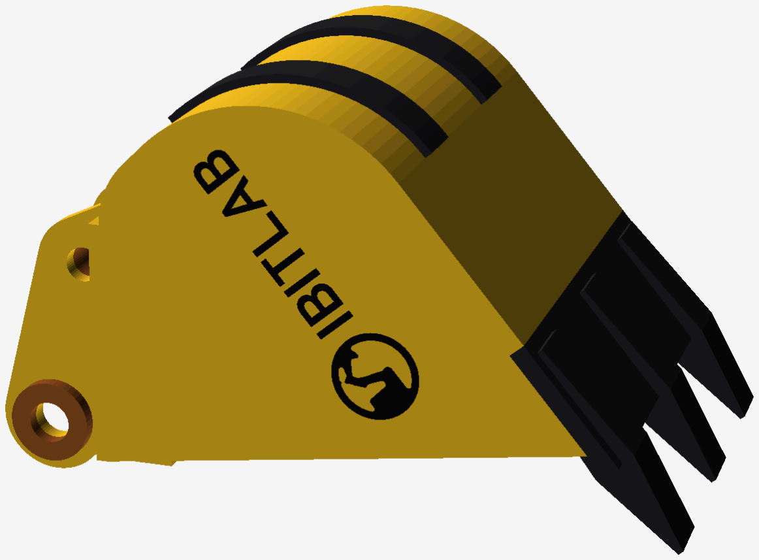
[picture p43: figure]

вузол цілком

Складання набору 1:5: що до чого приклеюється | Ihor Ivaniuk · @IBITLAB | 2026-09-24 · с. 16 / 24

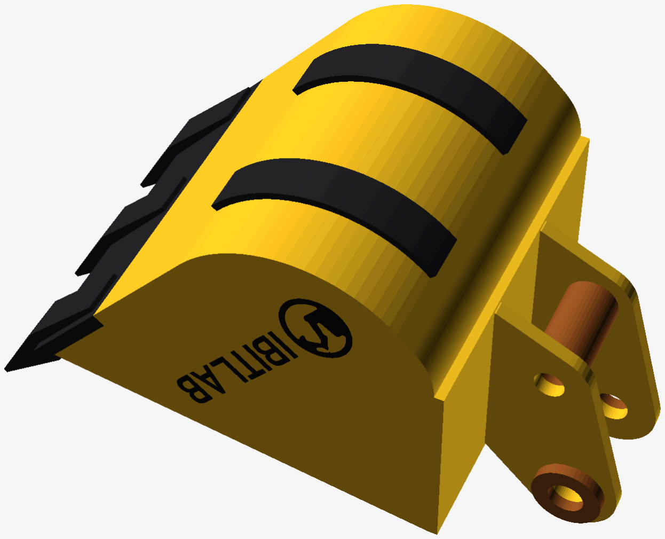
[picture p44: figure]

кріплення зблизька: два вуха, розпірка осі Q між ними, бобишки осі E зовні

Крок | Файл | К-сть | Габарит друку, мм | Ескіз | Куди | Як
3.1 | 18_bk_shell | 1 | 58.3 × 52.1 × 57.6 | ескіз 3.1 | основа вузла | Уже зігнута: полиця → R55 на 45° → спинка → R115 на 95° → дно; ставити порожниною догори
3.2 | 19_bk_side_L | 1 | 67.0 × 52.1 × 1.2 | ескіз 3.2 | з лівого боку обичайки | По всьому контуру обичайки; логотип — НАЗОВНІ. Ліва — якщо дивитись від колони на ківш
3.3 | 19_bk_side_R | 1 | 67.0 × 52.1 × 1.2 | ескіз 3.3 | з правого боку обичайки | Дзеркальна до лівої: так само по контуру, логотип — НАЗОВНІ
3.4 | 20_bk_top | 1 | 34.0 × 60.0 × 1.6 | — | на обичайку і верхні кромки боковин | Накладка, на яку потім стануть вуха
3.5 | 21_bk_lip_rib | 1 | 8.0 × 57.6 × 1.6 | — | під передню кромку верху | Ребро губи
Складання набору 1:5: що до чого приклеюється | Ihor Ivaniuk · @IBITLAB | 2026-09-24 · с. 17 / 24

Крок | Файл | К-сть | Габарит друку, мм | Ескіз | Куди | Як
3.6 | 22_bk_ear | 2 | 23.2 × 44.4 × 2.4 | ескіз 3.6 | на накладку верху | Відступ 4 мм (0.8 друкованих) від кожної кромки накладки; вісь E звисає на 16 мм позаду її задньої кромки. Решта розмірів — розділ «Де саме стають накладні деталі»
3.7 | 41_bk_spacer_Q | 1 | Ø9.0 × 16.4 | — | між вухами, вісь Q | Приварити до ОБОХ вух — це розпірка, а не втулка обертання
3.8 | 40_bk_boss_E | 2 | Ø12.0 × 2.0 | — | зовні вух, вісь E | По одній бобишці зовні кожного вуха
3.9 | 23_bk_edge | 1 | 20.0 × 60.0 × 2.4 | — | на передню кромку дна | Ніж; фаска 34° — догори
3.10 | 24_bk_tooth | 3 | 22.4 × 26.1 × 8.0 | — | на ніж | Три зуби вилкою охоплюють ніж
3.11 | 25_bk_wear | 2 | 37.1 × 9.8 × 8.0 | — | знизу на п'яту | Смуги зносу, уже вигнуті по радіусу п'яти

### Аркуші ескізів до цього розділу (контур і розміри В МЕТАЛІ, масштаб не дотриманий)

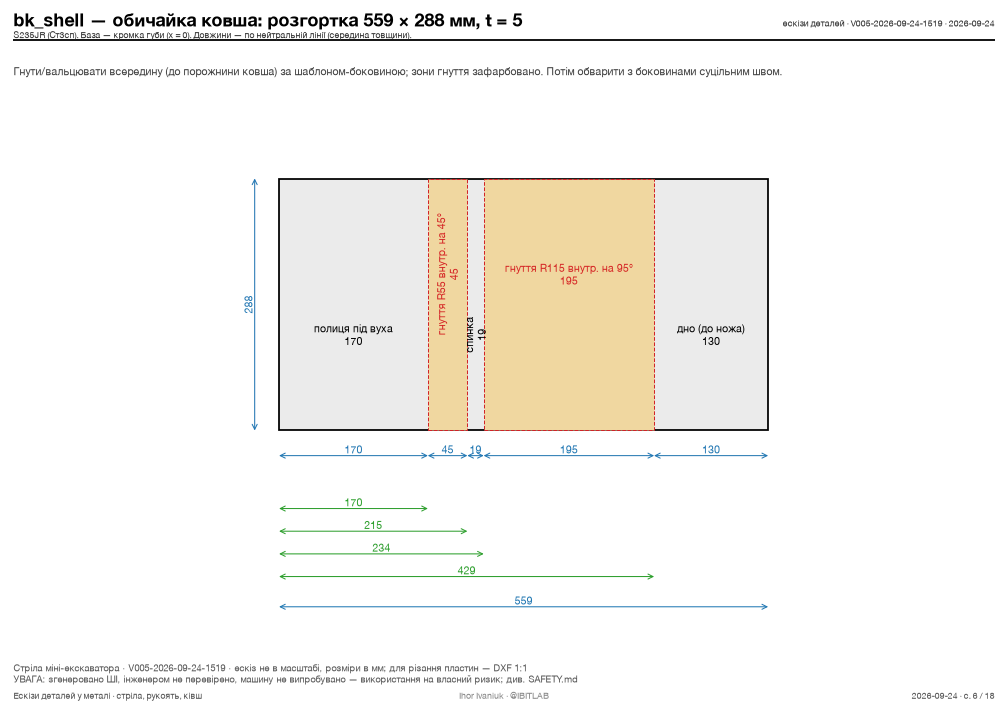
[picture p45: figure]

Ескіз 3.1 · 06_bk_shell

Складання набору 1:5: що до чого приклеюється | Ihor Ivaniuk · @IBITLAB | 2026-09-24 · с. 18 / 24

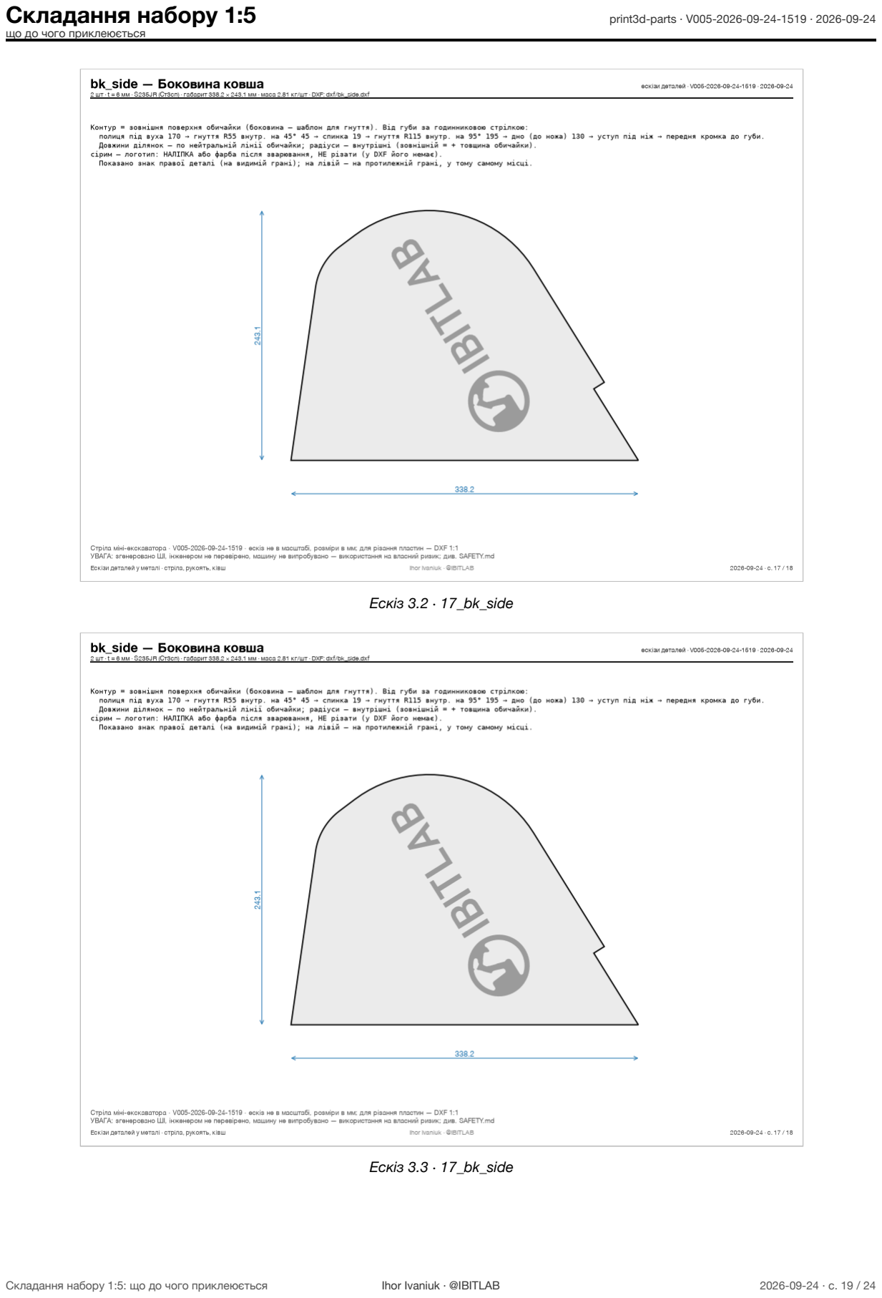
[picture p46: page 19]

Ескіз 3.2 · 17_bk_side

Ескіз 3.3 · 17_bk_side

Складання набору 1:5: що до чого приклеюється | Ihor Ivaniuk · @IBITLAB | 2026-09-24 · с. 19 / 24

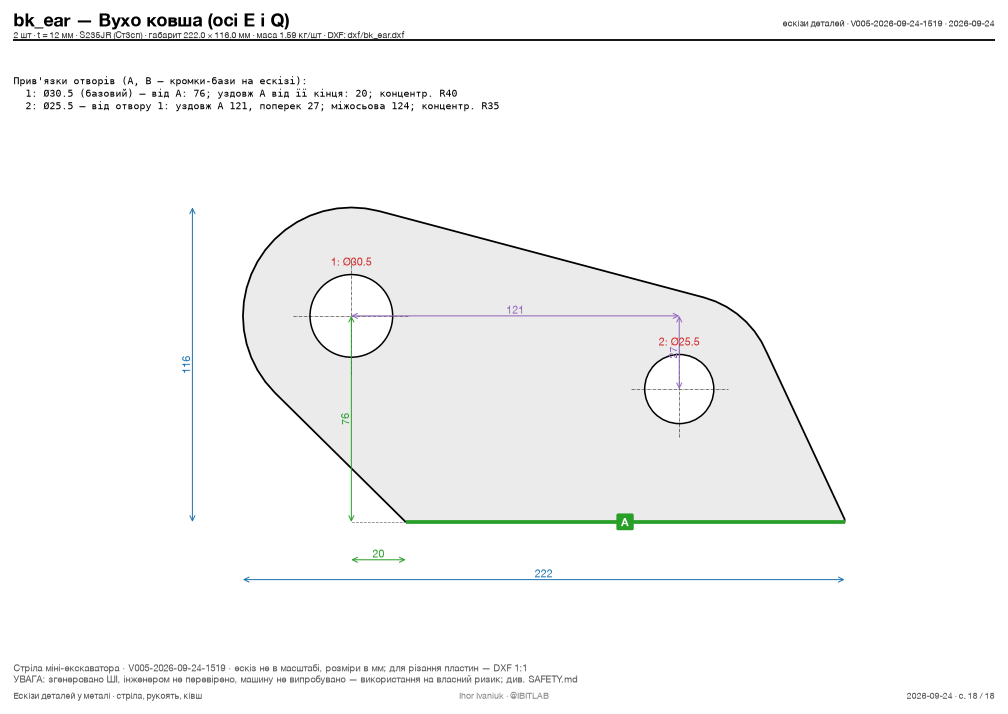
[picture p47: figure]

Ескіз 3.6 · 18_bk_ear

Складання набору 1:5: що до чого приклеюється | Ihor Ivaniuk · @IBITLAB | 2026-09-24 · с. 20 / 24

## 4. Важільна система

Крок | Файл | К-сть | Габарит друку, мм | Ескіз | Куди | Як
4.1 | 16_rocker_plate | 2 | 71.7 × 15.8 × 2.0 | ескіз 4.1 | основа коромисла | Дві пластини: отвір R сідає на рукоять, отвір J — до штока циліндра ковша
4.2 | 38_J_boss | 2 | Ø8.2 × 5.5 | — | зсередини пластин коромисла, вісь J | Упритул до вушка циліндра — без них палець J працює на згин
4.3 | 17_link_plate | 2 | 54.8 × 63.3 × 2.0 | ескіз 4.3 | основа тяги | Дві пластини
4.4 | 39_link_boss | 4 | Ø10.0 × 5.0 | — | зовні пластин тяги, осі J і Q | По дві бобишки на пластину, чотири на вузол

### Аркуші ескізів до цього розділу (контур і розміри В МЕТАЛІ, масштаб не дотриманий)

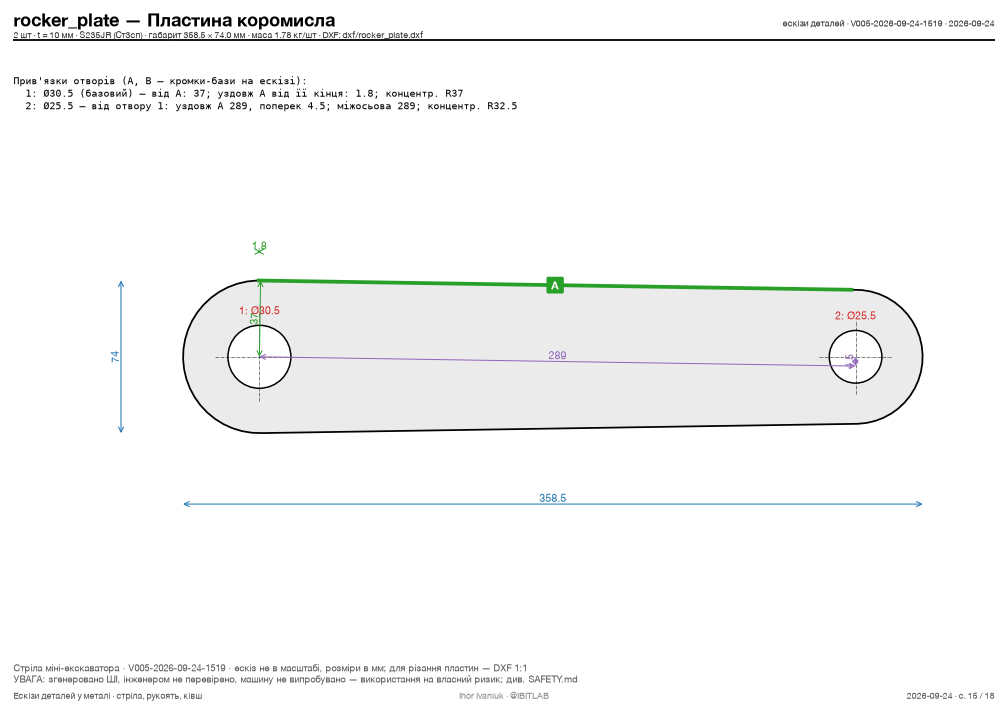
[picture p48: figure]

Ескіз 4.1 · 15_rocker_plate

Складання набору 1:5: що до чого приклеюється | Ihor Ivaniuk · @IBITLAB | 2026-09-24 · с. 21 / 24

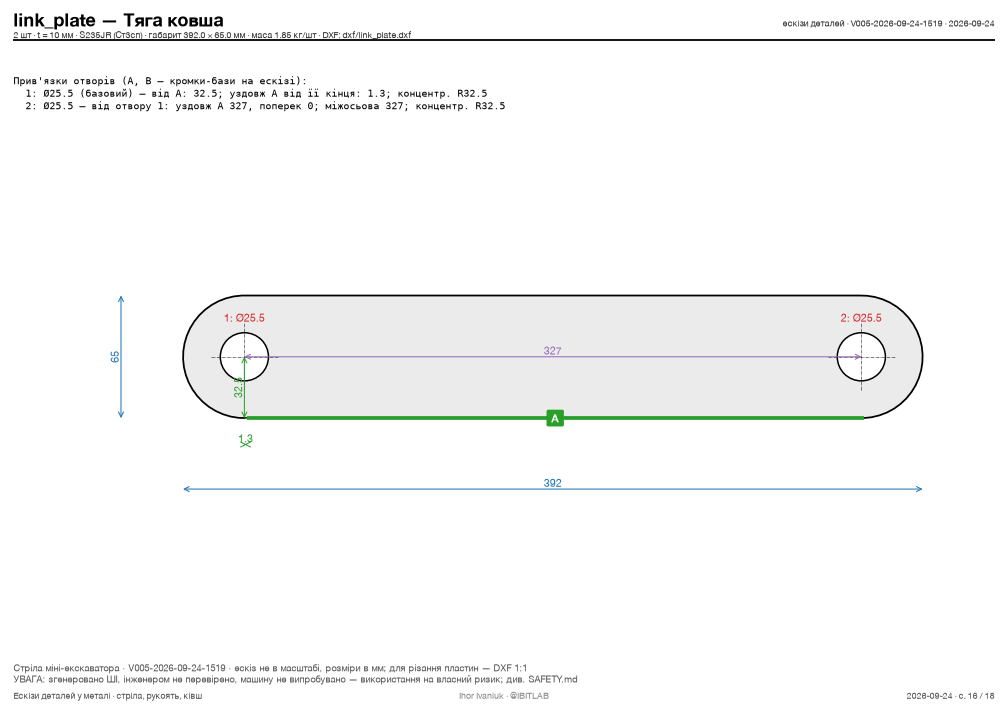
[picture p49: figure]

Ескіз 4.3 · 16_link_plate

## 5. Колона

Крок | Файл | К-сть | Габарит друку, мм | Ескіз | Куди | Як
5.1 | 26_post_plate | 2 | 50.0 × 112.0 × 2.4 | — | схема опори | Дві плити з осями A і C. Це не готовий вузол: рами причепа в моделі ще немає

## 6. Гідроциліндри

Крок | Файл | К-сть | Габарит друку, мм | Ескіз | Куди | Як
6.1 | 27_cyl_boom_body | 1 | 130.8 × 18.0 × 15.2 | — | — | Гільза циліндра стріли Ø63, канал під шток глухий
6.2 | 28_cyl_boom_rod | 1 | 124.8 × 11.6 × 8.0 | — | у гільзу циліндра стріли | Шток має ходити — НЕ клеїти
6.3 | 29_cyl_stick_body | 1 | 110.3 × 14.8 × 12.0 | — | — | Гільза циліндра рукояті Ø50
6.4 | 30_cyl_stick_rod | 1 | 104.3 × 10.6 × 5.0 | — | у гільзу циліндра рукояті | Шток має ходити — НЕ клеїти
6.5 | 31_cyl_bucket_body | 1 | 92.3 × 14.8 × 12.0 | — | — | Гільза циліндра ковша Ø50
6.6 | 32_cyl_bucket_rod | 1 | 84.3 × 10.6 × 5.0 | — | у гільзу циліндра ковша | Шток має ходити — НЕ клеїти
Складання набору 1:5: що до чого приклеюється | Ihor Ivaniuk · @IBITLAB | 2026-09-24 · с. 22 / 24

## 7. Складання на пальцях

Крок | Файл | К-сть | Габарит друку, мм | Ескіз | Куди | Як
7.1 | 43_pin_A | 1 | Ø7.2 × 36.9 | — | стріла на плити колони | Крізь втулку A; голівка пальця заходить першою
7.2 | 44_pin_C | 1 | Ø7.2 × 36.9 | — | база циліндра стріли на плити колони | НЕ плутати з пальцем D: цей проходить крізь обидві плити колони, тож удвічі довший (Ø30×182 проти Ø30×74). За довжиною він однаковий із пальцем A
7.3 | 45_pin_B | 1 | Ø7.2 × 26.1 | — | п'ята рукояті у вилку B стріли | Разом із шайбами наступного кроку
7.4 | 42_washer_B | 2 | Ø15.2 × 0.4 | — | на палець B, з боків пакета рукояті | Вибирають зазор між вилкою 80 і пакетом 76 — по 2 мм на бік
7.5 | 46_pin_D | 1 | Ø7.2 × 15.3 | — | шток циліндра стріли у вилку D | —
7.6 | 48_pin_F | 1 | Ø6.2 × 14.7 | — | база циліндра рукояті у вежу F | —
7.7 | 49_pin_G | 1 | Ø6.2 × 19.7 | — | шток циліндра рукояті у п'яту G | Між щоками, крізь розпірні втулки G
7.8 | 47_pin_E | 1 | Ø7.2 × 30.5 | — | ківш на кінець рукояті | Крізь втулку E, вуха ковша і зовнішні бобишки
7.9 | 53_pin_R | 1 | Ø7.2 × 20.9 | — | коромисло на накладки кінця рукояті | Крізь втулку R
7.10 | 50_pin_H | 1 | Ø6.2 × 14.7 | — | база циліндра ковша у вилку H | —
7.11 | 51_pin_J | 1 | Ø6.2 × 40.1 | — | шток циліндра ковша і тяги на коромислі | Найдовший палець Ø25 разом із Q
7.12 | 52_pin_Q | 1 | Ø6.2 × 40.1 | — | тяга у вуха ковша | Крізь розпірку Q

## Позначення

Ескіз — аркуш із контуром і розмірами деталі В МЕТАЛІ. Саме за ним упізнаєте пластину, коли на столі лежать три схожі. Аркушів немає у смуг, круглих деталей і пальців: їхні розміри цілком описані рядком специфікації.
Габарит друку — виміряний зі STL, у міліметрах надрукованої деталі. Розмір у металі (лист 8 мм, труба 120×80×5 тощо) — у BOM.md і parts.tsv .
Числа в колонці Як — це розміри В МЕТАЛІ, як їх бачить модель (отвір Ø66, проміжок 30 мм). На надрукованій деталі вони вп'ятеро менші: Ø66 → 13.2 мм, проміжок 30 → 6 мм. Так зроблено навмисно — за цими числами деталь упізнається на кресленнях і в BOM.
К-сть — скільки штук цього файлу в наборі; дзеркальні пари друкуються з одного файлу, тож ліва й права деталь однакові.
Складання набору 1:5: що до чого приклеюється | Ihor Ivaniuk · @IBITLAB | 2026-09-24 · с. 23 / 24

Кроки 1–5 — вузли, їх можна складати в будь-якому порядку між собою. Крок 6 (циліндри) і 7 (пальці) —

Складання набору 1:5: що до чого приклеюється | Ihor Ivaniuk · @IBITLAB | 2026-09-24 · с. 24 / 24

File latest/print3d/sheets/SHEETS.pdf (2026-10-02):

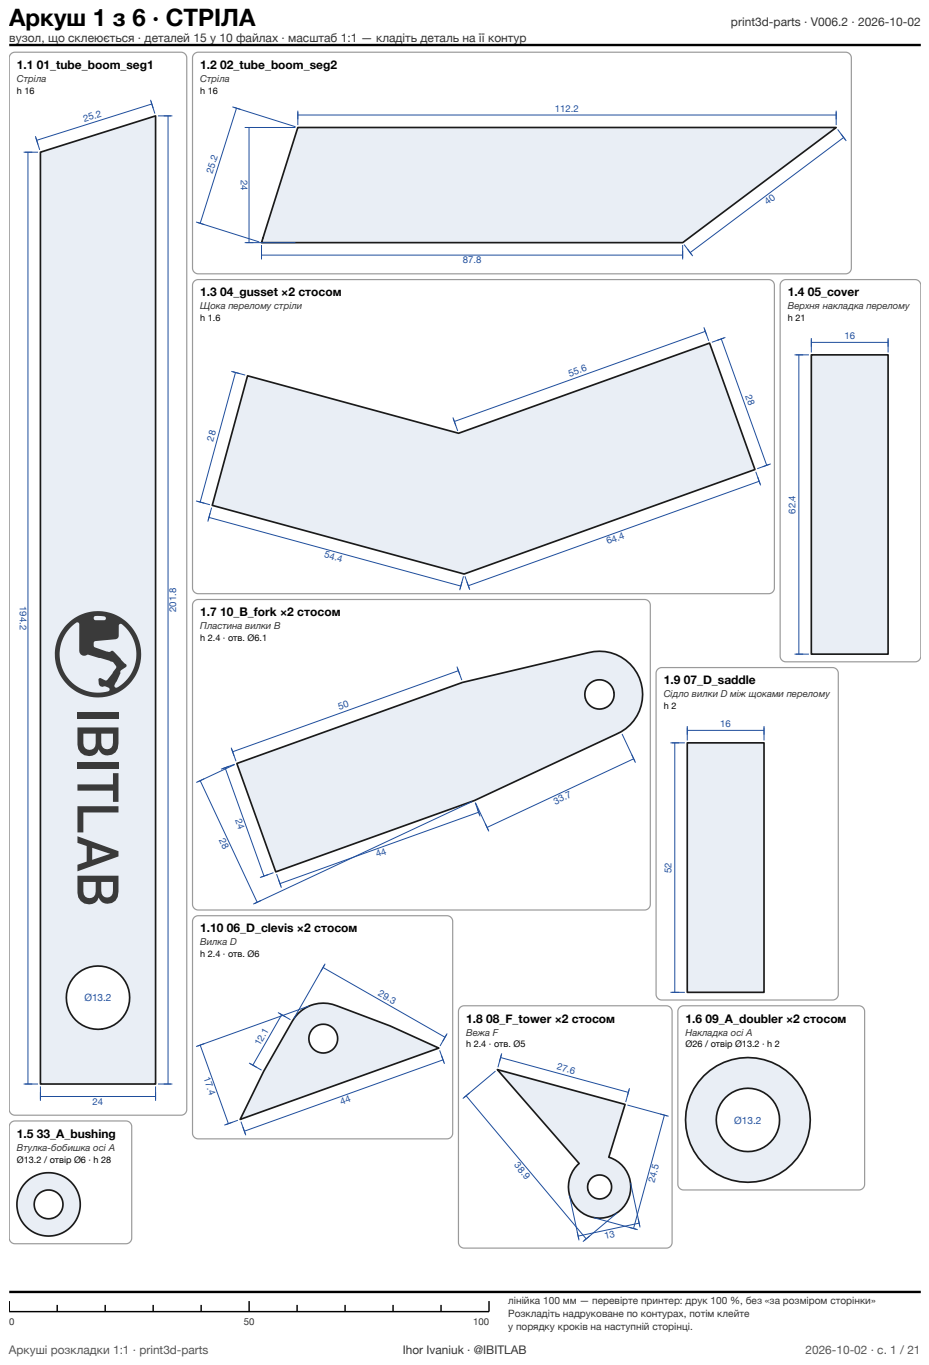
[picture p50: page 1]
Аркуш 1 з 6 · СТРІЛА; print3d-parts · V006.2 · 2026-10-02; 1.2 02_tube_boom_seg2 Стріла h 16; 1.3 04_gusset ×2 стосом Щока перелому стріли h 1.6; 1.7 10_B_fork ×2 стосом Пластина вилки B h 2.4 · отв. Ø6.1; 1.4 05_cover Верхня накладка перелому h 21; 1.10 06_D_clevis ×2 стосом Вилка D h 2.4 · отв. Ø6; 1.8 08_F_tower ×2 стосом Вежа F h 2.4 · отв. Ø5; 1.6 09_A_doubler ×2 стосом Накладка осі A Ø26 / отвір Ø13.2 · h 2; 1.5 33_A_bushing Втулка-бобишка осі A Ø13.2 / отвір Ø6 · h 28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

вузол, що склеюється · деталей 15 у 10 файлах · масштаб 1:1 — кладіть деталь на її контур
1.1 01_tube_boom_seg1
Стріла

1.9 07_D_saddle
Сідло вилки D між щоками перелому

лінійка 100 мм — перевірте принтер: друк 100 %, без «за розміром сторінки»
Розкладіть надруковане по контурах, потім клейте
у порядку кроків на наступній сторінці.

## Аркуш 1 · Стріла — порядок склеювання

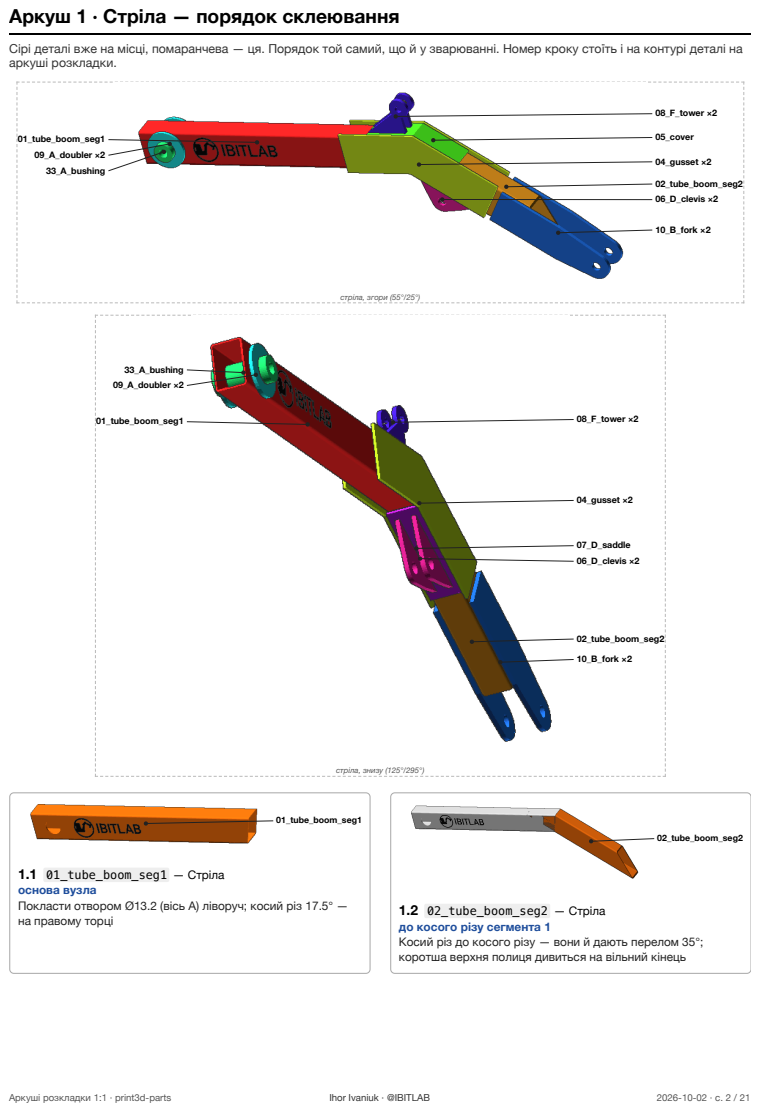
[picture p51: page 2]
01_tube_boom_seg1 09_A_doubler ×2 33_A_bushing; 08_F_tower ×2; 05_cover; 04_gusset ×2; 02_tube_boom_seg2 06_D_clevis ×2; 10_B_fork ×2; стріла, згори (55°/25°); 33_A_bushing 09_A_doubler ×2; 01_tube_boom_seg1; 07_D_saddle 06_D_clevis ×2; 02_tube_boom_seg2; стріла, знизу (125°/295°); Аркуші розкладки 1:1 · print3d-parts; Ihor Ivaniuk · @IBITLAB

Сірі деталі вже на місці, помаранчева — ця. Порядок той самий, що й у зварюванні. Номер кроку стоїть і на контурі деталі на
аркуші розкладки.

1.1 01_tube_boom_seg1 — Стріла
основа вузла
Покласти отвором Ø13.2 (вісь A) ліворуч; косий різ 17.5° —
на правому торці

1.2 02_tube_boom_seg2 — Стріла
до косого різу сегмента 1
Косий різ до косого різу — вони й дають перелом 35°;
коротша верхня полиця дивиться на вільний кінець

Щоки перекривають шов перелому; нижня кромка — урівень

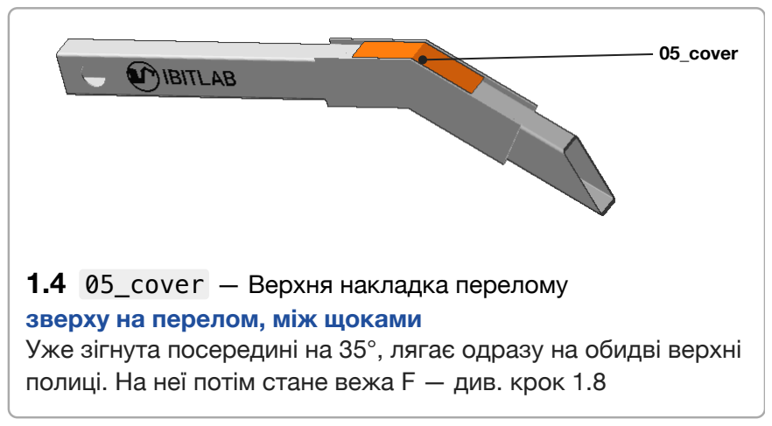
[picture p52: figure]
05_cover; 1.4 05_cover — Верхня накладка перелому зверху на перелом, між щоками

Уже зігнута посередині на 35°, лягає одразу на обидві верхні полиці. На неї потім стане вежа F — див. крок 1.8

Наскрізь крізь обидві стінки; виступає з боків порівну —

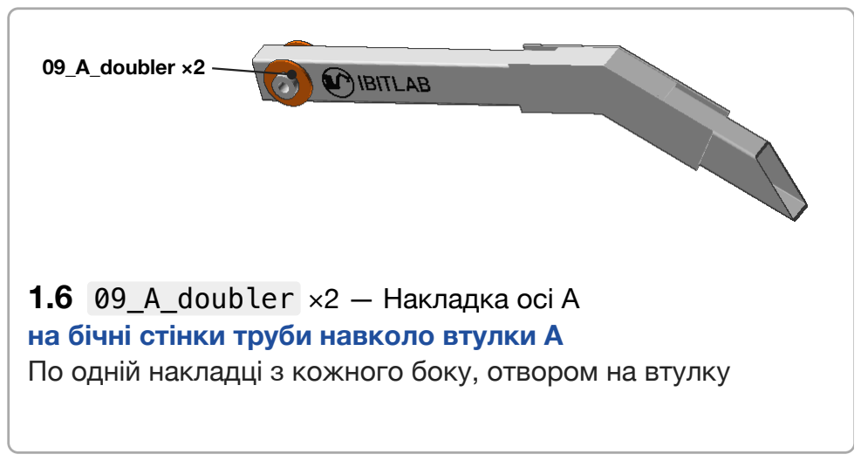
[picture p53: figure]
09_A_doubler ×2; 1.6 09_A_doubler ×2 — Накладка осі A на бічні стінки труби навколо втулки A

По одній накладці з кожного боку, отвором на втулку

Дві пластини; між ними потім заходить п'ята рукояті

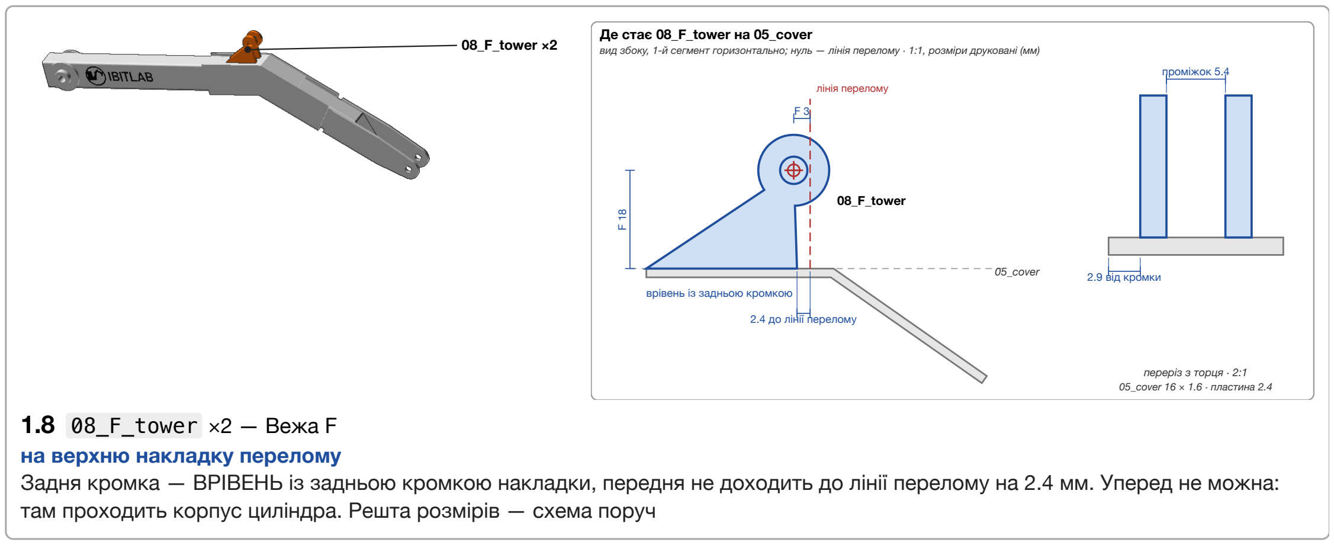
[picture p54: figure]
08_F_tower ×2; Де стає 08_F_tower на 05_cover; лінія перелому; 2.4 до лінії перелому; врівень із задньою кромкою; 08_F_tower; 05_cover; проміжок 5.4; 2.9 від кромки; переріз з торця · 2:1 05_cover 16 × 1.6 · пластина 2.4; 1.8 08_F_tower ×2 — Вежа F на верхню накладку перелому

вид збоку, 1-й сегмент горизонтально; нуль — лінія перелому · 1:1, розміри друковані (мм)

Задня кромка — ВРІВЕНЬ із задньою кромкою накладки, передня не доходить до лінії перелому на 2.4 мм. Уперед не можна: там проходить корпус циліндра. Решта розмірів — схема поруч

Аркуші розкладки 1:1 · print3d-parts | Ihor Ivaniuk · @IBITLAB | 2026-10-02 · с. 3 / 21

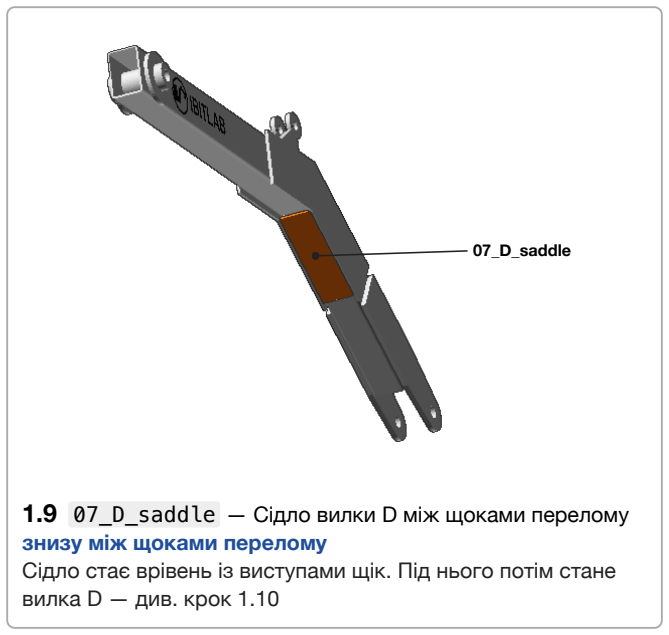
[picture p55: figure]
07_D_saddle; знизу між щоками перелому; вилка D — див. крок 1.10

1.9 07_D_saddle — Сідло вилки D між щоками перелому

Сідло стає врівень із виступами щік. Під нього потім стане

вид збоку, вісь кронштейна горизонтально; нуль — задня кромка сідла · 1:1, розміри друковані (мм)

Відступ 4.0 мм від кожного торця сідла, отвір — рівно посередині його довжини, проміжок 6 мм. Решта розмірів — схема поруч

Аркуші розкладки 1:1 · print3d-parts | Ihor Ivaniuk · @IBITLAB | 2026-10-02 · с. 4 / 21

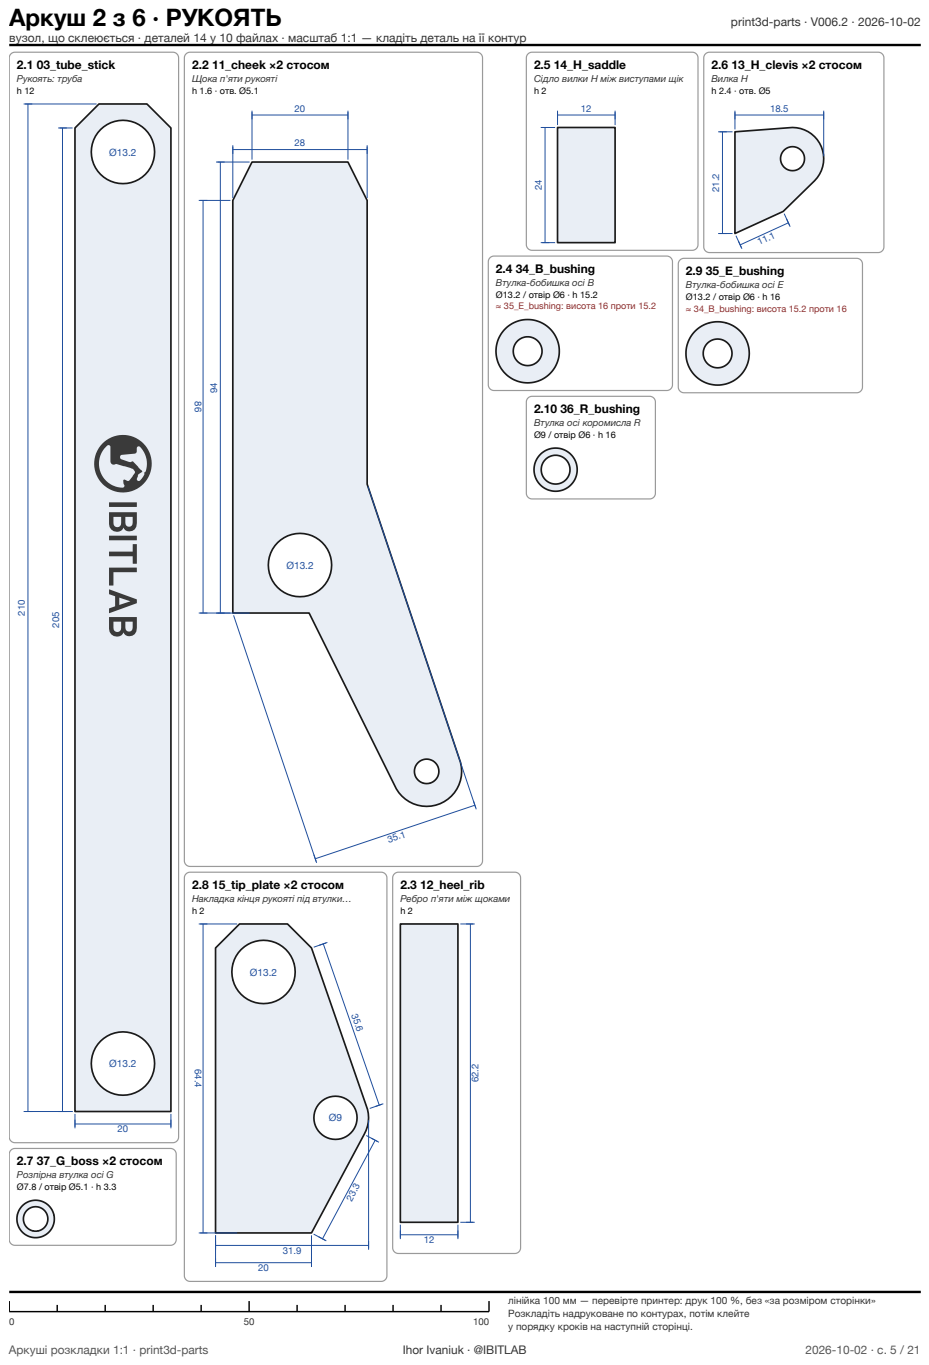
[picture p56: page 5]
Аркуш 2 з 6 · РУКОЯТЬ; print3d-parts · V006.2 · 2026-10-02; 2.3 12_heel_rib Ребро п'яти між щоками h 2; 2.6 13_H_clevis ×2 стосом Вилка H h 2.4 · отв. Ø5; 2.10 36_R_bushing Втулка осі коромисла R Ø9 / отвір Ø6 · h 16; Аркуші розкладки 1:1 · print3d-parts; Ihor Ivaniuk · @IBITLAB

вузол, що склеюється · деталей 14 у 10 файлах · масштаб 1:1 — кладіть деталь на її контур
2.1 03_tube_stick
Рукоять: труба

2.2 11_cheek ×2 стосом
Щока п'яти рукояті
h 1.6 · отв. Ø5.1

2.5 14_H_saddle
Сідло вилки H між виступами щік

2.4 34_B_bushing
Втулка-бобишка осі B
Ø13.2 / отвір Ø6 · h 15.2
≈ 35_E_bushing: висота 16 проти 15.2

2.9 35_E_bushing
Втулка-бобишка осі E
Ø13.2 / отвір Ø6 · h 16
≈ 34_B_bushing: висота 15.2 проти 16

2.8 15_tip_plate ×2 стосом
Накладка кінця рукояті під втулки…

2.7 37_G_boss ×2 стосом
Розпірна втулка осі G
Ø7.8 / отвір Ø5.1 · h 3.3

лінійка 100 мм — перевірте принтер: друк 100 %, без «за розміром сторінки»
Розкладіть надруковане по контурах, потім клейте
у порядку кроків на наступній сторінці.

## Аркуш 2 · Рукоять — порядок склеювання

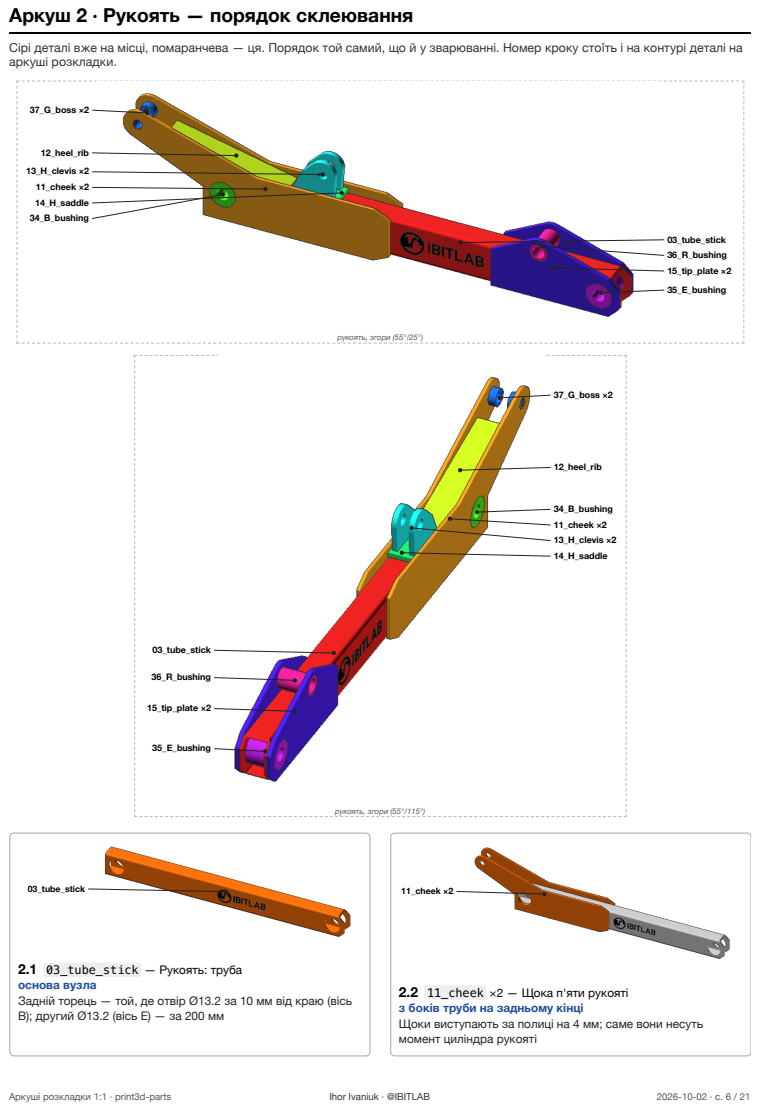
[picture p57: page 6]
37_G_boss ×2; 12_heel_rib; 13_H_clevis ×2 11_cheek ×2 14_H_saddle 34_B_bushing; 03_tube_stick 36_R_bushing 15_tip_plate ×2; 35_E_bushing; рукоять, згори (55°/25°); 03_tube_stick; 36_R_bushing; 15_tip_plate ×2; 34_B_bushing 11_cheek ×2 13_H_clevis ×2 14_H_saddle; рукоять, згори (55°/115°); 11_cheek ×2; Аркуші розкладки 1:1 · print3d-parts; Ihor Ivaniuk · @IBITLAB

Сірі деталі вже на місці, помаранчева — ця. Порядок той самий, що й у зварюванні. Номер кроку стоїть і на контурі деталі на
аркуші розкладки.

2.1 03_tube_stick — Рукоять: труба
основа вузла
Задній торець — той, де отвір Ø13.2 за 10 мм від краю (вісь
B); другий Ø13.2 (вісь E) — за 200 мм

2.2 11_cheek ×2 — Щока п'яти рукояті
з боків труби на задньому кінці
Щоки виступають за полиці на 4 мм; саме вони несуть
момент циліндра рукояті

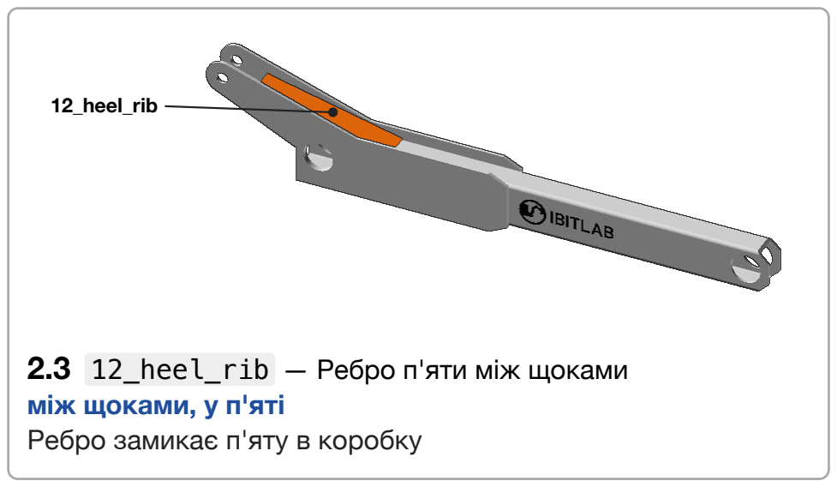
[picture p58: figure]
12_heel_rib; між щоками, у п'яті Ребро замикає п'яту в коробку

2.3 12_heel_rib — Ребро п'яти між щоками

в отвір Ø13.2 за 10 мм від заднього торця

2.5 14_H_saddle — Сідло вилки H між виступами щік

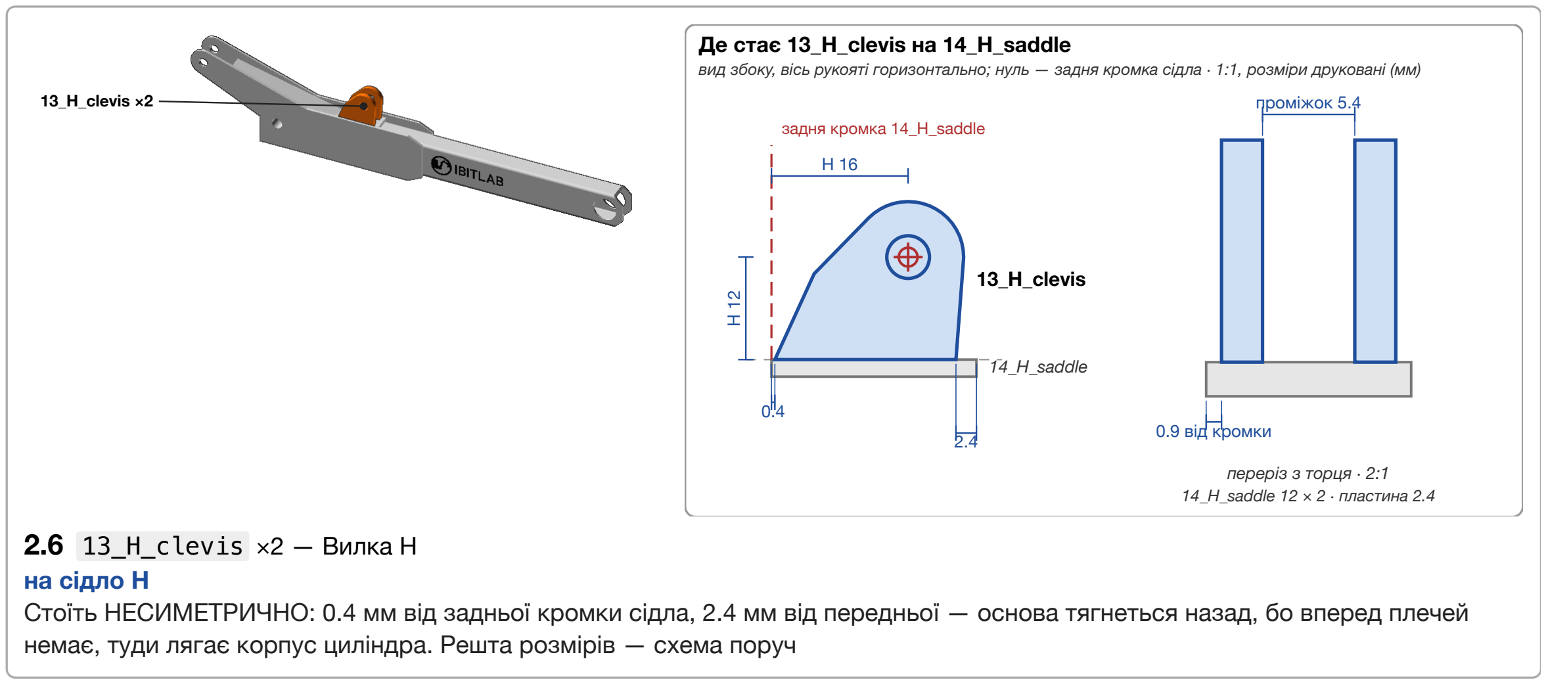
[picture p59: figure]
13_H_clevis ×2; Де стає 13_H_clevis на 14_H_saddle; задня кромка 14_H_saddle; 13_H_clevis; 14_H_saddle; проміжок 5.4; 0.9 від кромки; переріз з торця · 2:1 14_H_saddle 12 × 2 · пластина 2.4; 2.6 13_H_clevis ×2 — Вилка H на сідло H

вид збоку, вісь рукояті горизонтально; нуль — задня кромка сідла · 1:1, розміри друковані (мм)

Стоїть НЕСИМЕТРИЧНО: 0.4 мм від задньої кромки сідла, 2.4 мм від передньої — основа тягнеться назад, бо вперед плечей немає, туди лягає корпус циліндра. Решта розмірів — схема поруч

2.7 37_G_boss ×2 — Розпірна втулка осі G

Розпірні втулки, по одній на щоку: вони задають проміжок

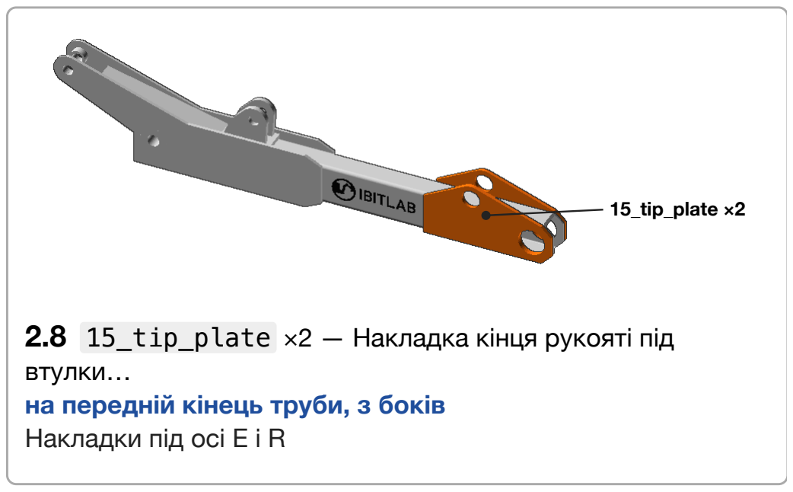
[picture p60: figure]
15_tip_plate ×2; втулки… на передній кінець труби, з боків Накладки під осі E і R

2.8 15_tip_plate ×2 — Накладка кінця рукояті під

Аркуші розкладки 1:1 · print3d-parts | Ihor Ivaniuk · @IBITLAB | 2026-10-02 · с. 7 / 21

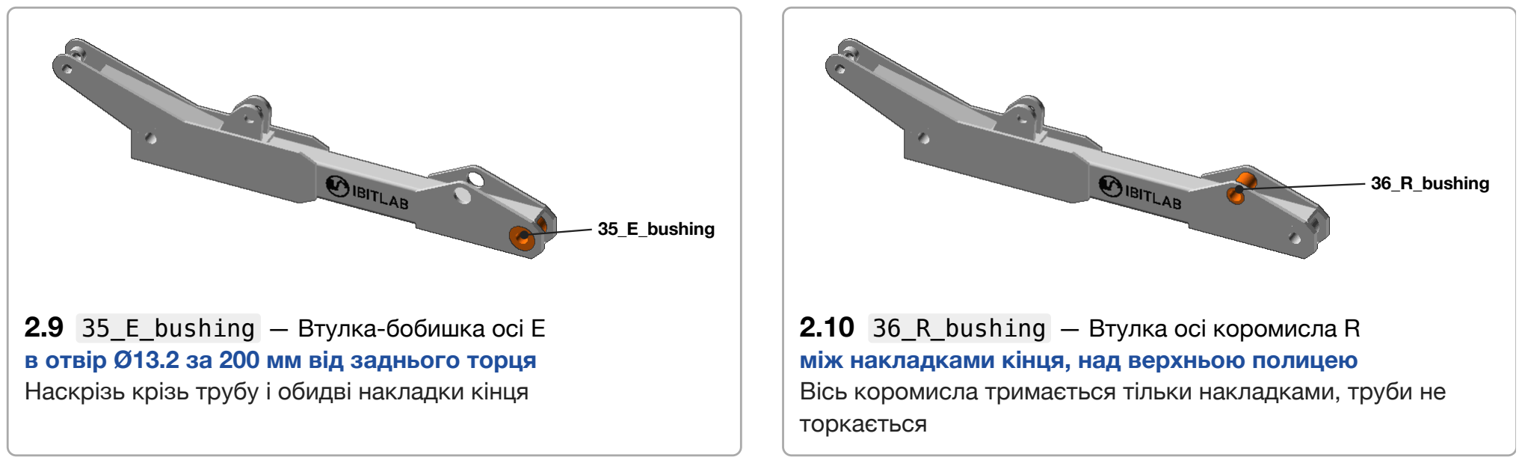
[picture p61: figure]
35_E_bushing; 2.9 35_E_bushing — Втулка-бобишка осі E; 36_R_bushing; торкається

в отвір Ø13.2 за 200 мм від заднього торця Наскрізь крізь трубу і обидві накладки кінця

2.10 36_R_bushing — Втулка осі коромисла R
між накладками кінця, над верхньою полицею
Вісь коромисла тримається тільки накладками, труби не
Аркуші розкладки 1:1 · print3d-parts | Ihor Ivaniuk · @IBITLAB | 2026-10-02 · с. 8 / 21

Аркуш 3 з 6 · КІВШ | print3d-parts · V006.2 · 2026-10-02

вузол, що склеюється · деталей 16 у 11 файлах · масштаб 1:1 — кладіть деталь на її контур

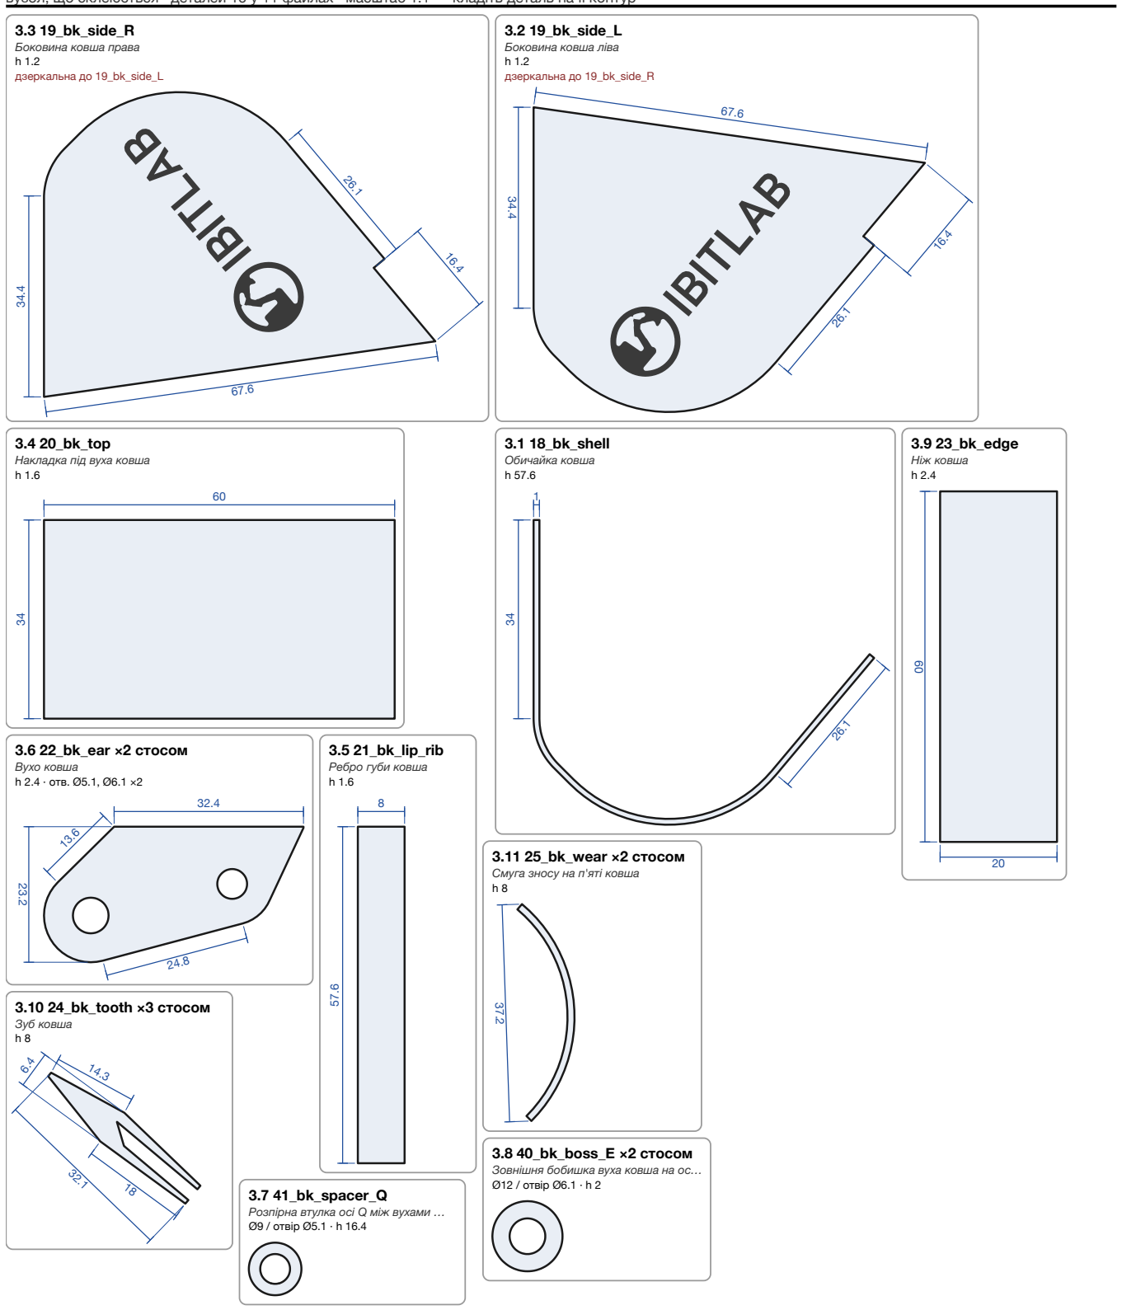
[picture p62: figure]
3.3 19_bk_side_R Боковина ковша права h 1.2 дзеркальна до 19_bk_side_L; 3.2 19_bk_side_L Боковина ковша ліва h 1.2 дзеркальна до 19_bk_side_R; 3.1 18_bk_shell Обичайка ковша h 57.6; 3.4 20_bk_top Накладка під вуха ковша h 1.6; 3.9 23_bk_edge Ніж ковша h 2.4; 3.6 22_bk_ear ×2 стосом Вухо ковша h 2.4 · отв. Ø5.1, Ø6.1 ×2; 3.5 21_bk_lip_rib Ребро губи ковша h 1.6; 3.10 24_bk_tooth ×3 стосом Зуб ковша h 8; 3.11 25_bk_wear ×2 стосом Смуга зносу на п'яті ковша h 8; 3.8 40_bk_boss_E ×2 стосом Зовнішня бобишка вуха ковша на ос… Ø12 / отвір Ø6.1 · h 2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

0 | 50 | 100

лінійка 100 мм — перевірте принтер: друк 100 %, без «за розміром сторінки» Розкладіть надруковане по контурах, потім клейте
у порядку кроків на наступній сторінці.
Аркуші розкладки 1:1 · print3d-parts | Ihor Ivaniuk · @IBITLAB | 2026-10-02 · с. 9 / 21

## Аркуш 3 · Ківш — порядок склеювання

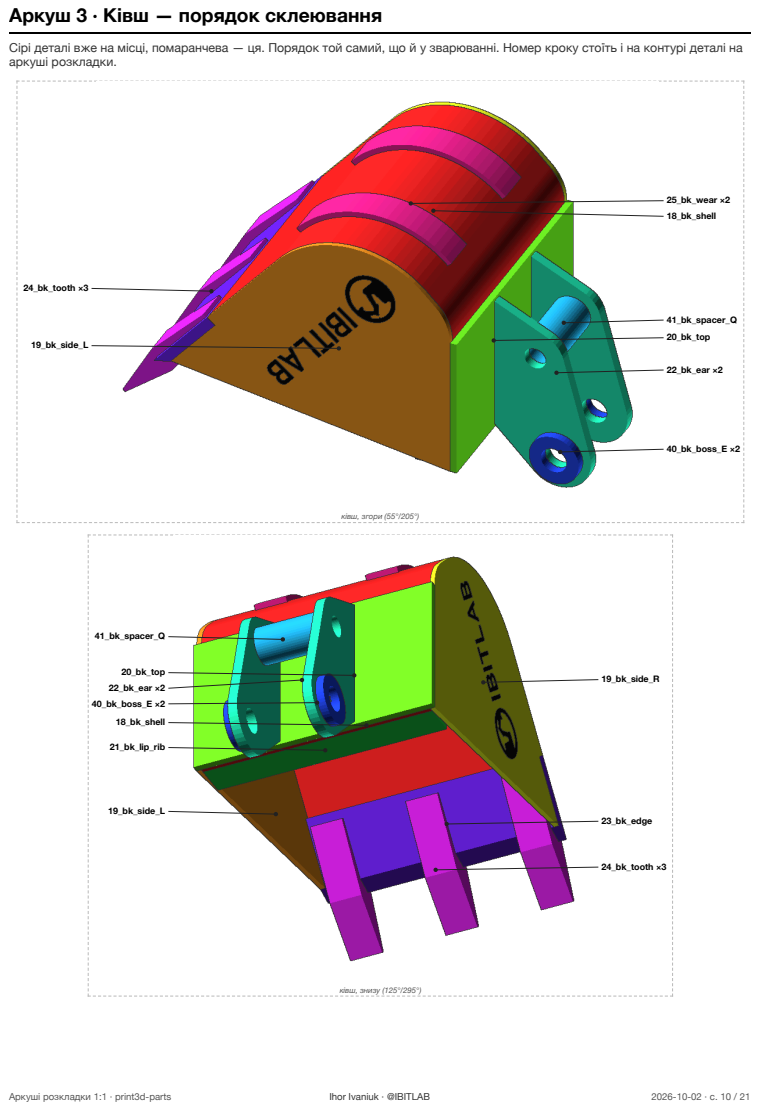
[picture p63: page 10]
24_bk_tooth ×3; 19_bk_side_L; 25_bk_wear ×2 18_bk_shell; 41_bk_spacer_Q; 20_bk_top; 22_bk_ear ×2; 40_bk_boss_E ×2; ківш, згори (55°/205°); 20_bk_top 22_bk_ear ×2 40_bk_boss_E ×2; 18_bk_shell; 21_bk_lip_rib; 19_bk_side_R; 23_bk_edge; ківш, знизу (125°/295°); Аркуші розкладки 1:1 · print3d-parts; Ihor Ivaniuk · @IBITLAB

Сірі деталі вже на місці, помаранчева — ця. Порядок той самий, що й у зварюванні. Номер кроку стоїть і на контурі деталі на
аркуші розкладки.

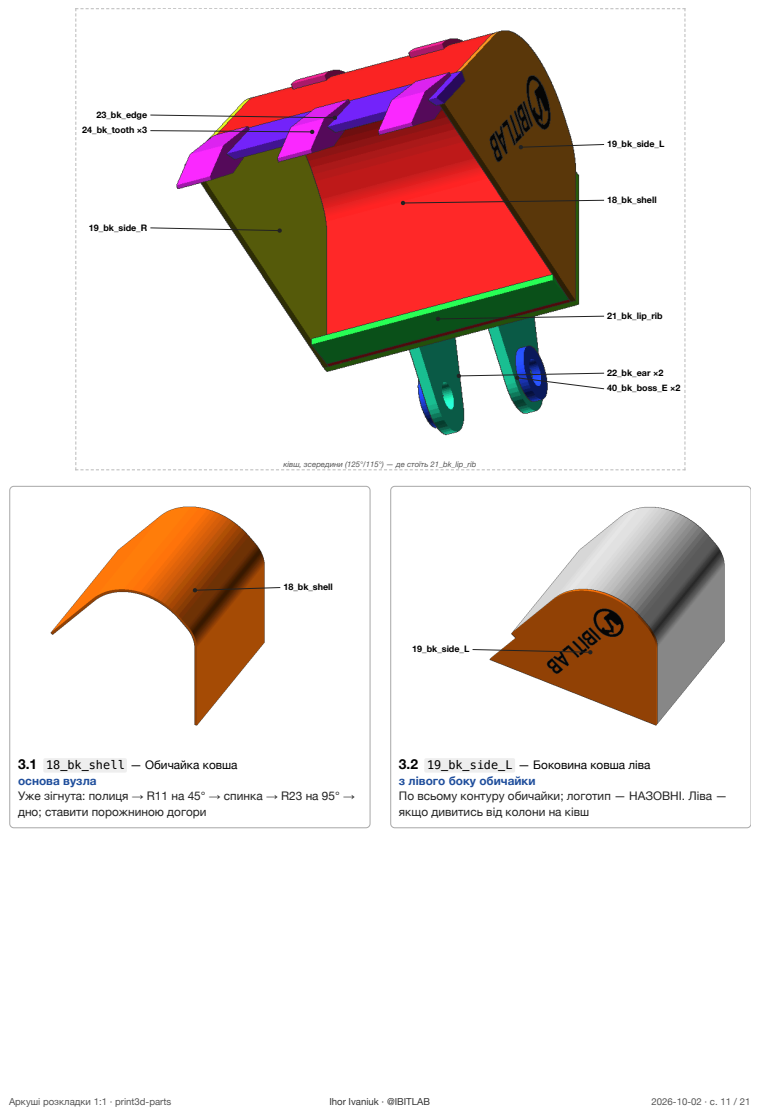
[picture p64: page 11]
23_bk_edge 24_bk_tooth ×3; 19_bk_side_R; 19_bk_side_L; 18_bk_shell; 21_bk_lip_rib; 22_bk_ear ×2 40_bk_boss_E ×2; Аркуші розкладки 1:1 · print3d-parts; Ihor Ivaniuk · @IBITLAB

ківш, зсередини (125°/115°) — де стоїть 21_bk_lip_rib

3.1 18_bk_shell — Обичайка ковша
основа вузла
Уже зігнута: полиця → R11 на 45° → спинка → R23 на 95° →
дно; ставити порожниною догори

3.2 19_bk_side_L — Боковина ковша ліва
з лівого боку обичайки
По всьому контуру обичайки; логотип — НАЗОВНІ. Ліва —
якщо дивитись від колони на ківш

19_bk_side_R; 3.3 19_bk_side_R — Боковина ковша права з правого боку обичайки; НАЗОВНІ

Дзеркальна до лівої: так само по контуру, логотип —

22_bk_ear ×2; Де стає 22_bk_ear на 20_bk_top; задня кромка 20_bk_top; 22_bk_ear; 20_bk_top; проміжок 16.4; 19.4 від кромки; переріз з торця · 1:1 20_bk_top 60 × 1.6 · пластина 2.4; 3.6 22_bk_ear ×2 — Вухо ковша на накладку верху

вид збоку, накладка горизонтально; нуль — задня кромка накладки · 1:1, розміри друковані (мм)

Відступ 0.8 мм від кожної кромки накладки; вісь E звисає на 3.2 мм позаду її задньої кромки. Решта розмірів — схема поруч

Аркуші розкладки 1:1 · print3d-parts | Ihor Ivaniuk · @IBITLAB | 2026-10-02 · с. 12 / 21


41_bk_spacer_Q

3.7 41_bk_spacer_Q — Розпірна втулка осі Q між вухами …
між вухами, вісь Q
Приварити до ОБОХ вух — це розпірка, а не втулка обертання

40_bk_boss_E ×2

3.8 40_bk_boss_E ×2 — Зовнішня бобишка вуха ковша на ос…
зовні вух, вісь E
По одній бобишці зовні кожного вуха

23_bk_edge

3.9 23_bk_edge — Ніж ковша на передню кромку дна
Ніж; фаска 34° — догори

24_bk_tooth ×3

3.10 24_bk_tooth ×3 — Зуб ковша на ніж
Три зуби вилкою охоплюють ніж

25_bk_wear ×2

3.11 25_bk_wear ×2 — Смуга зносу на п'яті ковша знизу на п'яту
Смуги зносу, уже вигнуті по радіусу п'яти
Аркуші розкладки 1:1 · print3d-parts | Ihor Ivaniuk · @IBITLAB | 2026-10-02 · с. 13 / 21

Аркуш 4 з 6 · КОРОМИСЛО І ТЯГА; print3d-parts · V006.2 · 2026-10-02; 4.1 16_rocker_plate ×2 стосом Пластина коромисла h 2 · отв. Ø5.1, Ø6.1 ×2; 4.2 38_J_boss ×2 стосом Бобишка осі J Ø8.2 / отвір Ø5.1 · h 5.5; 16_rocker_plate ×2; 38_J_boss ×2; коромисло, згори (55°/25°); 17_link_plate ×2; 39_link_boss ×4; тяга, згори (55°/25°); Аркуші розкладки 1:1 · print3d-parts; Ihor Ivaniuk · @IBITLAB

два вузли, що склеюються · деталей 10 у 4 файлах · масштаб 1:1 — кладіть деталь на її контур
4.3 17_link_plate ×2 стосом
Тяга ковша
h 2 · отв. Ø5.1 ×2

4.4 39_link_boss ×4 стосом
Бобишка тяги на осях J і Q
Ø10 / отвір Ø5.1 · h 5

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

## Аркуш 4 · Коромисло і тяга — порядок склеювання

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

4.1 16_rocker_plate ×2 — Пластина коромисла

Дві пластини: отвір R сідає на рукоять, отвір J — до штока Упритул до вушка циліндра — без них палець J працює на

4.4 39_link_boss ×4 — Бобишка тяги на осях J і Q

По дві бобишки на пластину, чотири на вузол

Аркуші розкладки 1:1 · print3d-parts | Ihor Ivaniuk · @IBITLAB | 2026-10-02 · с. 15 / 21

Аркуш 5 з 6 · КОЛОНА І ГІДРОЦИЛІНДРИ; print3d-parts · V006.2 · 2026-10-02; 6.2 28_cyl_boom_rod Шток циліндра стріли h 8 · отв. Ø6; 6.4 30_cyl_stick_rod Шток циліндра рукояті h 5 · отв. Ø5; 6.6 32_cyl_bucket_rod Шток циліндра ковша h 5 · отв. Ø5; Аркуші розкладки 1:1 · print3d-parts; Ihor Ivaniuk · @IBITLAB

плити колони — стосом; штоки в гільзи НЕ клеїти · деталей 8 у 7 файлах · масштаб 1:1 — кладіть деталь на її контур
6.1 27_cyl_boom_body
Гільза циліндра стріли з каналом …
h 15.2 · отв. Ø6

5.1 26_post_plate ×2 стосом
Плита поворотної колони
h 2.4 · отв. Ø6 ×2

6.3 29_cyl_stick_body
Гільза циліндра рукояті з каналом…
h 12 · отв. Ø5

6.5 31_cyl_bucket_body
Гільза циліндра ковша з каналом п…

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

## Аркуш 5 · Колона і гідроциліндри — порядок склеювання

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

аркуші розкладки.; 29_cyl_stick_body; 31_cyl_bucket_body; 32_cyl_bucket_rod; 27_cyl_boom_body; 28_cyl_boom_rod; 30_cyl_stick_rod; гідроциліндри, згори (55°/25°); аркуші.; 26_post_plate ×2; схема опори; моделі ще немає

6.1–6.6 27_cyl_boom_body , 28_cyl_boom_rod , 29_cyl_stick_body , 30_cyl_stick_rod , 31_cyl_bucket_body ,

Гідроциліндри: шток у свою гільзу. Шток має ходити — НЕ клеїти. Гільзи різняться довжиною і діаметром — див. розміри на

5.1 26_post_plate ×2 — Плита поворотної колони

Дві плити з осями A і C. Це не готовий вузол: рами причепа в

Аркуші розкладки 1:1 · print3d-parts | Ihor Ivaniuk · @IBITLAB | 2026-10-02 · с. 17 / 21

Аркуш 6 з 6 · ПАЛЬЦІ Й ШАЙБИ; print3d-parts · V006.2 · 2026-10-02; 7.2 44_pin_C Палець осі C Ø5.6 × 36.9 · голівка Ø7.2 = 43_pin_A (однакові); 7.6 48_pin_F Палець осі F Ø4.6 × 14.7 · голівка Ø6.2 = 50_pin_H (однакові); 7.10 50_pin_H Палець осі H Ø4.6 × 14.7 · голівка Ø6.2 = 48_pin_F (однакові); 7.11 51_pin_J Палець осі J Ø4.6 × 40.1 · голівка Ø6.2 = 52_pin_Q (однакові); 7.12 52_pin_Q Палець осі Q Ø4.6 × 40.1 · голівка Ø6.2 = 51_pin_J (однакові)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

з’єднання вузлів — не клеїти; кожен палець лежить окремо · деталей 13 у 12 файлах · масштаб 1:1 — кладіть деталь на її контур
7.1 43_pin_A
Палець осі A
Ø5.6 × 36.9 · голівка Ø7.2
= 44_pin_C (однакові)

7.4 42_washer_B ×2 стосом
Упорна шайба осі B
Ø15.2 / отвір Ø6.1 · h 0.4

уся машина, збоку (90°/115°)

лінійка 100 мм — перевірте принтер: друк 100 %, без «за розміром сторінки»
Пальці й шайби НЕ клеїти. Куди який — у виносках
на рендері й у кроках на наступній сторінці.

## Аркуш 6 · Пальці й шайби — порядок склеювання

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

Крізь втулку A; голівка пальця заходить першою

НЕ плутати з пальцем D: цей проходить крізь обидві плити колони, тож удвічі довший. За довжиною він однаковий із

Аркуші розкладки 1:1 · print3d-parts | Ihor Ivaniuk · @IBITLAB | 2026-10-02 · с. 19 / 21

45_pin_B; 42_washer_B ×2; 46_pin_D; 48_pin_F; 49_pin_G; 47_pin_E; Аркуші розкладки 1:1 · print3d-parts; Ihor Ivaniuk · @IBITLAB

7.4 42_washer_B ×2 — Упорна шайба осі B
на палець B, з боків пакета рукояті
Вибирають зазор між вилкою 16 і пакетом 15.2 — по 0.4 мм
на бік

7.3 45_pin_B — Палець осі B
п'ята рукояті у вилку B стріли
Разом із шайбами наступного кроку

7.6 48_pin_F — Палець осі F
база циліндра рукояті у вежу F

7.5 46_pin_D — Палець осі D
шток циліндра стріли у вилку D

7.8 47_pin_E — Палець осі E
ківш на кінець рукояті
Крізь втулку E, вуха ковша і зовнішні бобишки

7.7 49_pin_G — Палець осі G
шток циліндра рукояті у п'яту G
Між щоками, крізь розпірні втулки G

53_pin_R; 50_pin_H; 51_pin_J; 52_pin_Q; Аркуші розкладки 1:1 · print3d-parts; Ihor Ivaniuk · @IBITLAB

7.9 53_pin_R — Палець осі R
коромисло на накладки кінця рукояті
Крізь втулку R

7.10 50_pin_H — Палець осі H
база циліндра ковша у вилку H

7.12 52_pin_Q — Палець осі Q
тяга у вуха ковша
Крізь розпірку Q

7.11 51_pin_J — Палець осі J
шток циліндра ковша і тяги на коромислі
Найдовший палець разом із Q

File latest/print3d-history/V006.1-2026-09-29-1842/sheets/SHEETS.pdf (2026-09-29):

Аркуш 1 з 6 · СТРІЛА; print3d-parts · V006.1 · 2026-09-29; 1.2 02_tube_boom_seg2 Стріла h 16; 1.3 04_gusset ×2 стосом Щока перелому стріли h 1.6; 1.7 10_B_fork ×2 стосом Пластина вилки B h 2.4 · отв. Ø6.1; 1.4 05_cover Верхня накладка перелому h 21; 1.10 06_D_clevis ×2 стосом Вилка D h 2.4 · отв. Ø6; 1.8 08_F_tower ×2 стосом Вежа F h 2.4 · отв. Ø5; 1.6 09_A_doubler ×2 стосом Накладка осі A Ø26 / отвір Ø13.2 · h 2; 1.5 33_A_bushing Втулка-бобишка осі A Ø13.2 / отвір Ø6 · h 28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

вузол, що склеюється · деталей 15 у 10 файлах · масштаб 1:1 — кладіть деталь на її контур
1.1 01_tube_boom_seg1
Стріла

1.9 07_D_saddle
Сідло вилки D між щоками перелому

лінійка 100 мм — перевірте принтер: друк 100 %, без «за розміром сторінки»
Розкладіть надруковане по контурах, потім клейте
у порядку кроків на наступній сторінці.

## Аркуш 1 · Стріла — порядок склеювання

01_tube_boom_seg1 09_A_doubler ×2 33_A_bushing; 08_F_tower ×2; 05_cover; 04_gusset ×2; 02_tube_boom_seg2 06_D_clevis ×2; 10_B_fork ×2; стріла, згори (55°/25°); 33_A_bushing 09_A_doubler ×2; 01_tube_boom_seg1; 07_D_saddle 06_D_clevis ×2; 02_tube_boom_seg2; стріла, знизу (125°/295°); Аркуші розкладки 1:1 · print3d-parts; Ihor Ivaniuk · @IBITLAB

Сірі деталі вже на місці, помаранчева — ця. Порядок той самий, що й у зварюванні. Номер кроку стоїть і на контурі деталі на
аркуші розкладки.

1.1 01_tube_boom_seg1 — Стріла
основа вузла
Покласти отвором Ø13.2 (вісь A) ліворуч; косий різ 17.5° —
на правому торці

1.2 02_tube_boom_seg2 — Стріла
до косого різу сегмента 1
Косий різ до косого різу — вони й дають перелом 35°;
коротша верхня полиця дивиться на вільний кінець

Щоки перекривають шов перелому; нижня кромка — урівень

05_cover; 1.4 05_cover — Верхня накладка перелому зверху на перелом, між щоками

Уже зігнута посередині на 35°, лягає одразу на обидві верхні полиці. На неї потім стане вежа F — див. крок 1.8

Наскрізь крізь обидві стінки; виступає з боків порівну —

09_A_doubler ×2; 1.6 09_A_doubler ×2 — Накладка осі A на бічні стінки труби навколо втулки A

По одній накладці з кожного боку, отвором на втулку

Дві пластини; між ними потім заходить п'ята рукояті

08_F_tower ×2; Де стає 08_F_tower на 05_cover; лінія перелому; 2.4 до лінії перелому; врівень із задньою кромкою; 08_F_tower; 05_cover; проміжок 5.4; 2.9 від кромки; переріз з торця · 2:1 05_cover 16 × 1.6 · пластина 2.4; 1.8 08_F_tower ×2 — Вежа F на верхню накладку перелому

вид збоку, 1-й сегмент горизонтально; нуль — лінія перелому · 1:1, розміри друковані (мм)

Задня кромка — ВРІВЕНЬ із задньою кромкою накладки, передня не доходить до лінії перелому на 2.4 мм. Уперед не можна: там проходить корпус циліндра. Решта розмірів — схема поруч

Аркуші розкладки 1:1 · print3d-parts | Ihor Ivaniuk · @IBITLAB | 2026-09-29 · с. 3 / 21

07_D_saddle; знизу між щоками перелому; вилка D — див. крок 1.10

1.9 07_D_saddle — Сідло вилки D між щоками перелому

Сідло стає врівень із виступами щік. Під нього потім стане

вид збоку, вісь кронштейна горизонтально; нуль — задня кромка сідла · 1:1, розміри друковані (мм)

Відступ 4.0 мм від кожного торця сідла, отвір — рівно посередині його довжини, проміжок 6 мм. Решта розмірів — схема поруч

Аркуші розкладки 1:1 · print3d-parts | Ihor Ivaniuk · @IBITLAB | 2026-09-29 · с. 4 / 21

Аркуш 2 з 6 · РУКОЯТЬ; print3d-parts · V006.1 · 2026-09-29; 2.3 12_heel_rib Ребро п'яти між щоками h 2; 2.6 13_H_clevis ×2 стосом Вилка H h 2.4 · отв. Ø5; 2.10 36_R_bushing Втулка осі коромисла R Ø9 / отвір Ø6 · h 16; Аркуші розкладки 1:1 · print3d-parts; Ihor Ivaniuk · @IBITLAB

вузол, що склеюється · деталей 14 у 10 файлах · масштаб 1:1 — кладіть деталь на її контур
2.1 03_tube_stick
Рукоять: труба

2.2 11_cheek ×2 стосом
Щока п'яти рукояті
h 1.6 · отв. Ø5.1

2.5 14_H_saddle
Сідло вилки H між виступами щік

2.4 34_B_bushing
Втулка-бобишка осі B
Ø13.2 / отвір Ø6 · h 15.2
≈ 35_E_bushing: висота 16 проти 15.2

2.9 35_E_bushing
Втулка-бобишка осі E
Ø13.2 / отвір Ø6 · h 16
≈ 34_B_bushing: висота 15.2 проти 16

2.8 15_tip_plate ×2 стосом
Накладка кінця рукояті під втулки…

2.7 37_G_boss ×2 стосом
Розпірна втулка осі G
Ø7.8 / отвір Ø5.1 · h 3.3

лінійка 100 мм — перевірте принтер: друк 100 %, без «за розміром сторінки»
Розкладіть надруковане по контурах, потім клейте
у порядку кроків на наступній сторінці.

## Аркуш 2 · Рукоять — порядок склеювання

37_G_boss ×2; 12_heel_rib; 13_H_clevis ×2 11_cheek ×2 14_H_saddle 34_B_bushing; 03_tube_stick 36_R_bushing 15_tip_plate ×2; 35_E_bushing; рукоять, згори (55°/25°); 03_tube_stick; 36_R_bushing; 15_tip_plate ×2; 34_B_bushing 11_cheek ×2 13_H_clevis ×2 14_H_saddle; рукоять, згори (55°/115°); 11_cheek ×2; Аркуші розкладки 1:1 · print3d-parts; Ihor Ivaniuk · @IBITLAB

Сірі деталі вже на місці, помаранчева — ця. Порядок той самий, що й у зварюванні. Номер кроку стоїть і на контурі деталі на
аркуші розкладки.

2.1 03_tube_stick — Рукоять: труба
основа вузла
Задній торець — той, де отвір Ø13.2 за 10 мм від краю (вісь
B); другий Ø13.2 (вісь E) — за 200 мм

2.2 11_cheek ×2 — Щока п'яти рукояті
з боків труби на задньому кінці
Щоки виступають за полиці на 4 мм; саме вони несуть
момент циліндра рукояті

12_heel_rib; між щоками, у п'яті Ребро замикає п'яту в коробку

2.3 12_heel_rib — Ребро п'яти між щоками

в отвір Ø13.2 за 10 мм від заднього торця

2.5 14_H_saddle — Сідло вилки H між виступами щік

13_H_clevis ×2; Де стає 13_H_clevis на 14_H_saddle; задня кромка 14_H_saddle; 13_H_clevis; 14_H_saddle; проміжок 5.4; 0.9 від кромки; переріз з торця · 2:1 14_H_saddle 12 × 2 · пластина 2.4; 2.6 13_H_clevis ×2 — Вилка H на сідло H

вид збоку, вісь рукояті горизонтально; нуль — задня кромка сідла · 1:1, розміри друковані (мм)

Стоїть НЕСИМЕТРИЧНО: 0.4 мм від задньої кромки сідла, 2.4 мм від передньої — основа тягнеться назад, бо вперед плечей немає, туди лягає корпус циліндра. Решта розмірів — схема поруч

2.7 37_G_boss ×2 — Розпірна втулка осі G

Розпірні втулки, по одній на щоку: вони задають проміжок

15_tip_plate ×2; втулки… на передній кінець труби, з боків Накладки під осі E і R

2.8 15_tip_plate ×2 — Накладка кінця рукояті під

Аркуші розкладки 1:1 · print3d-parts | Ihor Ivaniuk · @IBITLAB | 2026-09-29 · с. 7 / 21

35_E_bushing; 2.9 35_E_bushing — Втулка-бобишка осі E; 36_R_bushing; торкається

в отвір Ø13.2 за 200 мм від заднього торця Наскрізь крізь трубу і обидві накладки кінця

2.10 36_R_bushing — Втулка осі коромисла R
між накладками кінця, над верхньою полицею
Вісь коромисла тримається тільки накладками, труби не
Аркуші розкладки 1:1 · print3d-parts | Ihor Ivaniuk · @IBITLAB | 2026-09-29 · с. 8 / 21

Аркуш 3 з 6 · КІВШ | print3d-parts · V006.1 · 2026-09-29

вузол, що склеюється · деталей 16 у 11 файлах · масштаб 1:1 — кладіть деталь на її контур

3.3 19_bk_side_R Боковина ковша права h 1.2 дзеркальна до 19_bk_side_L; 3.2 19_bk_side_L Боковина ковша ліва h 1.2 дзеркальна до 19_bk_side_R; 3.1 18_bk_shell Обичайка ковша h 57.6; 3.4 20_bk_top Накладка під вуха ковша h 1.6; 3.9 23_bk_edge Ніж ковша h 2.4; 3.6 22_bk_ear ×2 стосом Вухо ковша h 2.4 · отв. Ø5.1, Ø6.1 ×2; 3.5 21_bk_lip_rib Ребро губи ковша h 1.6; 3.10 24_bk_tooth ×3 стосом Зуб ковша h 8; 3.11 25_bk_wear ×2 стосом Смуга зносу на п'яті ковша h 8; 3.8 40_bk_boss_E ×2 стосом Зовнішня бобишка вуха ковша на ос… Ø12 / отвір Ø6.1 · h 2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

0 | 50 | 100

лінійка 100 мм — перевірте принтер: друк 100 %, без «за розміром сторінки» Розкладіть надруковане по контурах, потім клейте
у порядку кроків на наступній сторінці.
Аркуші розкладки 1:1 · print3d-parts | Ihor Ivaniuk · @IBITLAB | 2026-09-29 · с. 9 / 21

## Аркуш 3 · Ківш — порядок склеювання

24_bk_tooth ×3; 19_bk_side_L; 25_bk_wear ×2 18_bk_shell; 41_bk_spacer_Q; 20_bk_top; 22_bk_ear ×2; 40_bk_boss_E ×2; ківш, згори (55°/205°); 20_bk_top 22_bk_ear ×2 40_bk_boss_E ×2; 18_bk_shell; 21_bk_lip_rib; 19_bk_side_R; 23_bk_edge; ківш, знизу (125°/295°); Аркуші розкладки 1:1 · print3d-parts; Ihor Ivaniuk · @IBITLAB

Сірі деталі вже на місці, помаранчева — ця. Порядок той самий, що й у зварюванні. Номер кроку стоїть і на контурі деталі на
аркуші розкладки.

23_bk_edge 24_bk_tooth ×3; 19_bk_side_R; 19_bk_side_L; 18_bk_shell; 21_bk_lip_rib; 22_bk_ear ×2 40_bk_boss_E ×2; Аркуші розкладки 1:1 · print3d-parts; Ihor Ivaniuk · @IBITLAB

ківш, зсередини (125°/115°) — де стоїть 21_bk_lip_rib

3.1 18_bk_shell — Обичайка ковша
основа вузла
Уже зігнута: полиця → R11 на 45° → спинка → R23 на 95° →
дно; ставити порожниною догори

3.2 19_bk_side_L — Боковина ковша ліва
з лівого боку обичайки
По всьому контуру обичайки; логотип — НАЗОВНІ. Ліва —
якщо дивитись від колони на ківш

19_bk_side_R; 3.3 19_bk_side_R — Боковина ковша права з правого боку обичайки; НАЗОВНІ

Дзеркальна до лівої: так само по контуру, логотип —

22_bk_ear ×2; Де стає 22_bk_ear на 20_bk_top; задня кромка 20_bk_top; 22_bk_ear; 20_bk_top; проміжок 16.4; 19.4 від кромки; переріз з торця · 1:1 20_bk_top 60 × 1.6 · пластина 2.4; 3.6 22_bk_ear ×2 — Вухо ковша на накладку верху

вид збоку, накладка горизонтально; нуль — задня кромка накладки · 1:1, розміри друковані (мм)

Відступ 0.8 мм від кожної кромки накладки; вісь E звисає на 3.2 мм позаду її задньої кромки. Решта розмірів — схема поруч

Аркуші розкладки 1:1 · print3d-parts | Ihor Ivaniuk · @IBITLAB | 2026-09-29 · с. 12 / 21


41_bk_spacer_Q

3.7 41_bk_spacer_Q — Розпірна втулка осі Q між вухами …
між вухами, вісь Q
Приварити до ОБОХ вух — це розпірка, а не втулка обертання

40_bk_boss_E ×2

3.8 40_bk_boss_E ×2 — Зовнішня бобишка вуха ковша на ос…
зовні вух, вісь E
По одній бобишці зовні кожного вуха

23_bk_edge

3.9 23_bk_edge — Ніж ковша на передню кромку дна
Ніж; фаска 34° — догори

24_bk_tooth ×3

3.10 24_bk_tooth ×3 — Зуб ковша на ніж
Три зуби вилкою охоплюють ніж

25_bk_wear ×2

3.11 25_bk_wear ×2 — Смуга зносу на п'яті ковша знизу на п'яту
Смуги зносу, уже вигнуті по радіусу п'яти
Аркуші розкладки 1:1 · print3d-parts | Ihor Ivaniuk · @IBITLAB | 2026-09-29 · с. 13 / 21

Аркуш 4 з 6 · КОРОМИСЛО І ТЯГА; print3d-parts · V006.1 · 2026-09-29; 4.1 16_rocker_plate ×2 стосом Пластина коромисла h 2 · отв. Ø5.1, Ø6.1 ×2; 4.2 38_J_boss ×2 стосом Бобишка осі J Ø8.2 / отвір Ø5.1 · h 5.5; 16_rocker_plate ×2; 38_J_boss ×2; коромисло, згори (55°/25°); 17_link_plate ×2; 39_link_boss ×4; тяга, згори (55°/25°); Аркуші розкладки 1:1 · print3d-parts; Ihor Ivaniuk · @IBITLAB

два вузли, що склеюються · деталей 10 у 4 файлах · масштаб 1:1 — кладіть деталь на її контур
4.3 17_link_plate ×2 стосом
Тяга ковша
h 2 · отв. Ø5.1 ×2

4.4 39_link_boss ×4 стосом
Бобишка тяги на осях J і Q
Ø10 / отвір Ø5.1 · h 5

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

## Аркуш 4 · Коромисло і тяга — порядок склеювання

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

4.1 16_rocker_plate ×2 — Пластина коромисла

Дві пластини: отвір R сідає на рукоять, отвір J — до штока Упритул до вушка циліндра — без них палець J працює на

4.4 39_link_boss ×4 — Бобишка тяги на осях J і Q

По дві бобишки на пластину, чотири на вузол

Аркуші розкладки 1:1 · print3d-parts | Ihor Ivaniuk · @IBITLAB | 2026-09-29 · с. 15 / 21

Аркуш 5 з 6 · КОЛОНА І ГІДРОЦИЛІНДРИ; print3d-parts · V006.1 · 2026-09-29; 6.2 28_cyl_boom_rod Шток циліндра стріли h 8 · отв. Ø6; 6.4 30_cyl_stick_rod Шток циліндра рукояті h 5 · отв. Ø5; 6.6 32_cyl_bucket_rod Шток циліндра ковша h 5 · отв. Ø5; Аркуші розкладки 1:1 · print3d-parts; Ihor Ivaniuk · @IBITLAB

плити колони — стосом; штоки в гільзи НЕ клеїти · деталей 8 у 7 файлах · масштаб 1:1 — кладіть деталь на її контур
6.1 27_cyl_boom_body
Гільза циліндра стріли з каналом …
h 15.2 · отв. Ø6

5.1 26_post_plate ×2 стосом
Плита поворотної колони
h 2.4 · отв. Ø6 ×2

6.3 29_cyl_stick_body
Гільза циліндра рукояті з каналом…
h 12 · отв. Ø5

6.5 31_cyl_bucket_body
Гільза циліндра ковша з каналом п…

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

## Аркуш 5 · Колона і гідроциліндри — порядок склеювання

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

аркуші розкладки.; 29_cyl_stick_body; 31_cyl_bucket_body; 32_cyl_bucket_rod; 27_cyl_boom_body; 28_cyl_boom_rod; 30_cyl_stick_rod; гідроциліндри, згори (55°/25°); аркуші.; 26_post_plate ×2; схема опори; моделі ще немає

6.1–6.6 27_cyl_boom_body , 28_cyl_boom_rod , 29_cyl_stick_body , 30_cyl_stick_rod , 31_cyl_bucket_body ,

Гідроциліндри: шток у свою гільзу. Шток має ходити — НЕ клеїти. Гільзи різняться довжиною і діаметром — див. розміри на

5.1 26_post_plate ×2 — Плита поворотної колони

Дві плити з осями A і C. Це не готовий вузол: рами причепа в

Аркуші розкладки 1:1 · print3d-parts | Ihor Ivaniuk · @IBITLAB | 2026-09-29 · с. 17 / 21

Аркуш 6 з 6 · ПАЛЬЦІ Й ШАЙБИ; print3d-parts · V006.1 · 2026-09-29; 7.2 44_pin_C Палець осі C Ø5.6 × 36.9 · голівка Ø7.2 = 43_pin_A (однакові); 7.6 48_pin_F Палець осі F Ø4.6 × 14.7 · голівка Ø6.2 = 50_pin_H (однакові); 7.10 50_pin_H Палець осі H Ø4.6 × 14.7 · голівка Ø6.2 = 48_pin_F (однакові); 7.11 51_pin_J Палець осі J Ø4.6 × 40.1 · голівка Ø6.2 = 52_pin_Q (однакові); 7.12 52_pin_Q Палець осі Q Ø4.6 × 40.1 · голівка Ø6.2 = 51_pin_J (однакові)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

з’єднання вузлів — не клеїти; кожен палець лежить окремо · деталей 13 у 12 файлах · масштаб 1:1 — кладіть деталь на її контур
7.1 43_pin_A
Палець осі A
Ø5.6 × 36.9 · голівка Ø7.2
= 44_pin_C (однакові)

7.4 42_washer_B ×2 стосом
Упорна шайба осі B
Ø15.2 / отвір Ø6.1 · h 0.4

уся машина, збоку (90°/115°)

лінійка 100 мм — перевірте принтер: друк 100 %, без «за розміром сторінки»
Пальці й шайби НЕ клеїти. Куди який — у виносках
на рендері й у кроках на наступній сторінці.

## Аркуш 6 · Пальці й шайби — порядок склеювання

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

Крізь втулку A; голівка пальця заходить першою

НЕ плутати з пальцем D: цей проходить крізь обидві плити колони, тож удвічі довший. За довжиною він однаковий із

Аркуші розкладки 1:1 · print3d-parts | Ihor Ivaniuk · @IBITLAB | 2026-09-29 · с. 19 / 21

45_pin_B; 42_washer_B ×2; 46_pin_D; 48_pin_F; 49_pin_G; 47_pin_E; Аркуші розкладки 1:1 · print3d-parts; Ihor Ivaniuk · @IBITLAB

7.4 42_washer_B ×2 — Упорна шайба осі B
на палець B, з боків пакета рукояті
Вибирають зазор між вилкою 16 і пакетом 15.2 — по 0.4 мм
на бік

7.3 45_pin_B — Палець осі B
п'ята рукояті у вилку B стріли
Разом із шайбами наступного кроку

7.6 48_pin_F — Палець осі F
база циліндра рукояті у вежу F

7.5 46_pin_D — Палець осі D
шток циліндра стріли у вилку D

7.8 47_pin_E — Палець осі E
ківш на кінець рукояті
Крізь втулку E, вуха ковша і зовнішні бобишки

7.7 49_pin_G — Палець осі G
шток циліндра рукояті у п'яту G
Між щоками, крізь розпірні втулки G

53_pin_R; 50_pin_H; 51_pin_J; 52_pin_Q; Аркуші розкладки 1:1 · print3d-parts; Ihor Ivaniuk · @IBITLAB

7.9 53_pin_R — Палець осі R
коромисло на накладки кінця рукояті
Крізь втулку R

7.10 50_pin_H — Палець осі H
база циліндра ковша у вилку H

7.12 52_pin_Q — Палець осі Q
тяга у вуха ковша
Крізь розпірку Q

7.11 51_pin_J — Палець осі J
шток циліндра ковша і тяги на коромислі
Найдовший палець разом із Q

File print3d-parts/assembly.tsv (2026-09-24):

# Порядок складання набору print3d-parts. Читає sheets/make_sheets.py (картки кроків).
# Це знання про КОНСТРУКЦІЮ (що до чого приварюється в металі) — пишеться руками.
# Числа сюди не пишуться: назви, кількості й габарити підтягуються з parts.tsv
# і з виміряних STL. Кожен ключ із parts.tsv має бути тут рівно один раз —
# інакше make.sh зупиниться (крок «кроки складання»).
# крок | вузол | ключ_pp | куди | як
1.1 | 1. Стріла | tube_boom_seg1 | основа вузла | Покласти отвором Ø66 (вісь A) ліворуч; косий різ 17.5° — на правому торці
1.2 | 1. Стріла | tube_boom_seg2 | до косого різу сегмента 1 | Косий різ до косого різу — вони й дають перелом 35°; коротша верхня полиця дивиться на вільний кінець
1.3 | 1. Стріла | gusset | з обох боків стику труб | Щоки перекривають шов перелому; нижня кромка — урівень із нижньою полицею
1.4 | 1. Стріла | cover | зверху на перелом, між щоками | Уже зігнута посередині на 35°, лягає одразу на обидві верхні полиці. На неї потім стане вежа F — див. крок 1.8
1.5 | 1. Стріла | A_bushing | в отвір Ø66 сегмента 1 | Наскрізь крізь обидві стінки; виступає з боків порівну — втулка довша за ширину труби
1.6 | 1. Стріла | A_doubler | на бічні стінки труби навколо втулки A | По одній накладці з кожного боку, отвором на втулку
1.7 | 1. Стріла | B_fork | на передній торець сегмента 2, з боків | Дві пластини; між ними потім заходить п'ята рукояті
1.8 | 1. Стріла | F_tower | на верхню накладку перелому | Задня кромка — ВРІВЕНЬ із задньою кромкою накладки, передня не доходить до лінії перелому на 12 мм (2.4 друкованих). Уперед не можна: там проходить корпус циліндра. Решта розмірів — розділ «Де саме стають накладні деталі»
1.9 | 1. Стріла | D_saddle | знизу між щоками перелому | Сідло стає врівень із виступами щік. Під нього потім стане вилка D — див. крок 1.10
1.10 | 1. Стріла | D_clevis | на сідло D | Відступ 20 мм (4.0 друкованих) від кожного торця сідла, отвір — рівно посередині його довжини, проміжок 30 мм. Решта розмірів — розділ «Де саме стають накладні деталі»
2.1 | 2. Рукоять | tube_stick | основа вузла | Задній торець — той, де отвір Ø66 за 50 мм від краю (вісь B); другий Ø66 (вісь E) — за 1000 мм
2.2 | 2. Рукоять | cheek | з боків труби на задньому кінці | Щоки виступають за полиці на 20 мм; саме вони несуть момент циліндра рукояті
2.3 | 2. Рукоять | heel_rib | між щоками, у п'яті | Ребро замикає п'яту в коробку
2.4 | 2. Рукоять | B_bushing | в отвір Ø66 за 50 мм від заднього торця | Наскрізь крізь трубу і ОБИДВІ щоки
2.5 | 2. Рукоять | H_saddle | зверху між виступами щік | Сідло під вилку циліндра ковша
2.6 | 2. Рукоять | H_clevis | на сідло H | Стоїть НЕСИМЕТРИЧНО: 2 мм (0.4 друкованих) від задньої кромки сідла, 12 мм (2.4) від передньої — основа тягнеться назад, бо вперед плечей немає, туди лягає корпус циліндра. Решта розмірів — розділ «Де саме стають накладні деталі»
2.7 | 2. Рукоять | G_boss | на щоки ззовні, вісь G | Розпірні втулки, по одній на щоку: вони задають проміжок під вушко штока
2.8 | 2. Рукоять | tip_plate | на передній кінець труби, з боків | Накладки під осі E і R
2.9 | 2. Рукоять | E_bushing | в отвір Ø66 за 1000 мм від заднього торця | Наскрізь крізь трубу і обидві накладки кінця
2.10 | 2. Рукоять | R_bushing | між накладками кінця, над верхньою полицею | Вісь коромисла тримається тільки накладками, труби не торкається
3.1 | 3. Ківш | bk_shell | основа вузла | Уже зігнута: полиця → R55 на 45° → спинка → R115 на 95° → дно; ставити порожниною догори
3.2 | 3. Ківш | bk_side_L | з лівого боку обичайки | По всьому контуру обичайки; логотип — НАЗОВНІ. Ліва — якщо дивитись від колони на ківш
3.3 | 3. Ківш | bk_side_R | з правого боку обичайки | Дзеркальна до лівої: так само по контуру, логотип — НАЗОВНІ
3.4 | 3. Ківш | bk_top | на обичайку і верхні кромки боковин | Накладка, на яку потім стануть вуха
3.5 | 3. Ківш | bk_lip_rib | під передню кромку верху | Ребро губи
3.6 | 3. Ківш | bk_ear | на накладку верху | Відступ 4 мм (0.8 друкованих) від кожної кромки накладки; вісь E звисає на 16 мм позаду її задньої кромки. Решта розмірів — розділ «Де саме стають накладні деталі»
3.7 | 3. Ківш | bk_spacer_Q | між вухами, вісь Q | Приварити до ОБОХ вух — це розпірка, а не втулка обертання
3.8 | 3. Ківш | bk_boss_E | зовні вух, вісь E | По одній бобишці зовні кожного вуха
3.9 | 3. Ківш | bk_edge | на передню кромку дна | Ніж; фаска 34° — догори
3.10 | 3. Ківш | bk_tooth | на ніж | Три зуби вилкою охоплюють ніж
3.11 | 3. Ківш | bk_wear | знизу на п'яту | Смуги зносу, уже вигнуті по радіусу п'яти
4.1 | 4. Важільна система | rocker_plate | основа коромисла | Дві пластини: отвір R сідає на рукоять, отвір J — до штока циліндра ковша
4.2 | 4. Важільна система | J_boss | зсередини пластин коромисла, вісь J | Упритул до вушка циліндра — без них палець J працює на згин
4.3 | 4. Важільна система | link_plate | основа тяги | Дві пластини
4.4 | 4. Важільна система | link_boss | зовні пластин тяги, осі J і Q | По дві бобишки на пластину, чотири на вузол
5.1 | 5. Колона | post_plate | схема опори | Дві плити з осями A і C. Це не готовий вузол: рами причепа в моделі ще немає
6.1 | 6. Гідроциліндри | cyl_boom_body | — | Гільза циліндра стріли Ø63, канал під шток глухий
6.2 | 6. Гідроциліндри | cyl_boom_rod | у гільзу циліндра стріли | Шток має ходити — НЕ клеїти
6.3 | 6. Гідроциліндри | cyl_stick_body | — | Гільза циліндра рукояті Ø50
6.4 | 6. Гідроциліндри | cyl_stick_rod | у гільзу циліндра рукояті | Шток має ходити — НЕ клеїти
6.5 | 6. Гідроциліндри | cyl_bucket_body | — | Гільза циліндра ковша Ø50
6.6 | 6. Гідроциліндри | cyl_bucket_rod | у гільзу циліндра ковша | Шток має ходити — НЕ клеїти
7.1 | 7. Складання на пальцях | pin_A | стріла на плити колони | Крізь втулку A; голівка пальця заходить першою
7.2 | 7. Складання на пальцях | pin_C | база циліндра стріли на плити колони | НЕ плутати з пальцем D: цей проходить крізь обидві плити колони, тож удвічі довший (Ø30×182 проти Ø30×74). За довжиною він однаковий із пальцем A
7.3 | 7. Складання на пальцях | pin_B | п'ята рукояті у вилку B стріли | Разом із шайбами наступного кроку
7.4 | 7. Складання на пальцях | washer_B | на палець B, з боків пакета рукояті | Вибирають зазор між вилкою 80 і пакетом 76 — по 2 мм на бік
7.5 | 7. Складання на пальцях | pin_D | шток циліндра стріли у вилку D | —
7.6 | 7. Складання на пальцях | pin_F | база циліндра рукояті у вежу F | —
7.7 | 7. Складання на пальцях | pin_G | шток циліндра рукояті у п'яту G | Між щоками, крізь розпірні втулки G
7.8 | 7. Складання на пальцях | pin_E | ківш на кінець рукояті | Крізь втулку E, вуха ковша і зовнішні бобишки
7.9 | 7. Складання на пальцях | pin_R | коромисло на накладки кінця рукояті | Крізь втулку R
7.10 | 7. Складання на пальцях | pin_H | база циліндра ковша у вилку H | —
7.11 | 7. Складання на пальцях | pin_J | шток циліндра ковша і тяги на коромислі | Найдовший палець Ø25 разом із Q
7.12 | 7. Складання на пальцях | pin_Q | тяга у вуха ковша | Крізь розпірку Q

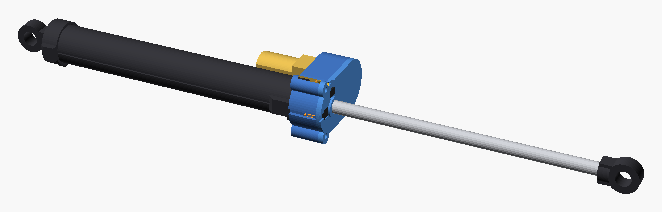
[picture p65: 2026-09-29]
latest/print3d-history/V006.1-2026-09-29-1842/m5_cylinders/img/boom_open.png

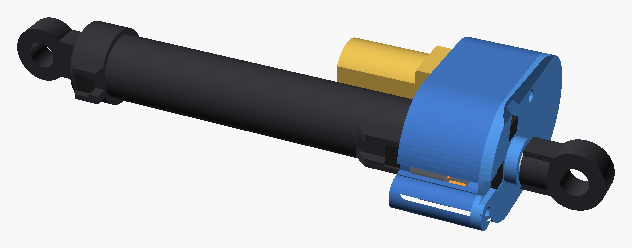
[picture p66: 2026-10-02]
latest/print3d/m5_cylinders/img/bucket_closed.png

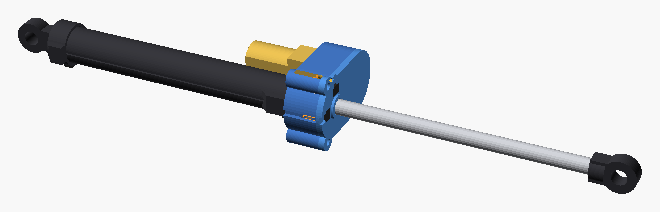
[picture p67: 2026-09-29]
latest/print3d-history/V006.1-2026-09-29-1842/m5_cylinders/img/stick_open.png

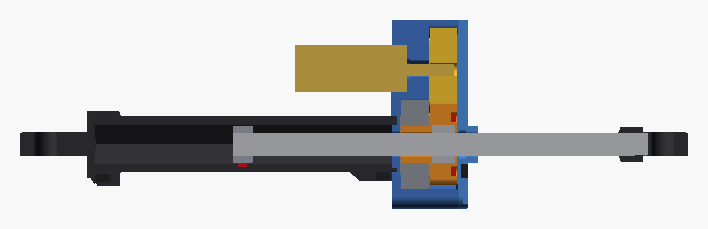
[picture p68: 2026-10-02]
latest/print3d/m5_cylinders/img/bucket_cut.png

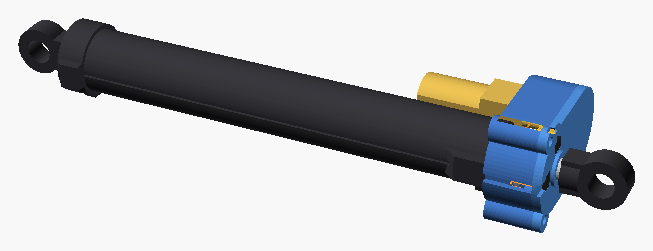
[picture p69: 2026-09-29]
latest/print3d-history/V006.1-2026-09-29-1842/m5_cylinders/img/boom_closed.png

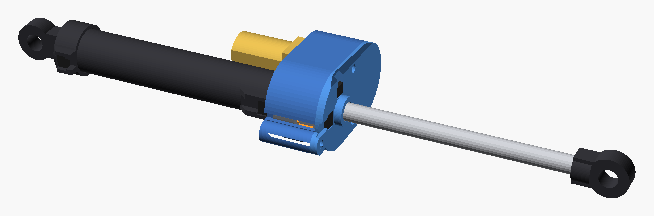
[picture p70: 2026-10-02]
latest/print3d/m5_cylinders/img/bucket_open.png

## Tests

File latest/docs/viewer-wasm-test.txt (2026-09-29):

✓ схема: 8 груп, 105 параметрів
✓ літерали параметрів
✓ легенда: 8 кольорів, усі є в моделі
✓ блок //<spacemouse> однаковий в обох версіях сторінки
✓ блок //<pose> однаковий в обох версіях сторінки
✓ блок //<viewjson> однаковий в обох версіях сторінки
✓ зіткнення AR: 8 випадків (стіна, підлога, стіл, сітка)
✓ зліпок кімнати: тінь, повторна поява, злиття, назавжди, карта глибин
✓ скан кімнати: 96 кадрів → 57124 трикутників у 48 шматках (стіни 36390, горизонтальні 19652), усі в межах 4 см, «людину» вичищено; затінення: лице й нормалі узгоджені, AO стіни 0.99, кута до 0.64
✓ переклад en: немає ключів: повний
✓ переклад en: зайві ключі: повний
✓ ключі t() з main.js у словнику: повний
✓ складені ключі: 27
✓ складені ключі у словнику: повний
✓ англійські назви груп: повний
✓ англійські описи параметрів: повний
✓ зайві записи у словнику параметрів: повний
✓ OpenSCAD-WASM: код 0, без попереджень, 3650 мс
✓ деталей: 12, вершин: 32889
✓ розрізання за Y коректне
✓ логотип на стрілі, рукояті, ковші й колоні
✓ зворотна задача: зуб стає на місце, похибка 2.3e-12 мм
✓ ківш без повороту: кути повертаються ті самі, похибка 2.8e-14°
✓ поза JS = echo моделі: зуб (1601.3, -858.9)

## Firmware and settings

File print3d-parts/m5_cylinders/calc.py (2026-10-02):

#!/usr/bin/env python3
"""Циліндри моделі 1:5 на шпильці M5: довжини, маса, сили, мотор і шестерні → CALC.md.

Схема — у README.md поруч: шпилька M5×0.8 — шток, гайка крутиться в шестерні в голові
циліндра, поруч паралельно N20.

Скрипт нічого не вибирає сам: мотор, шестерні й розміри гільзи — сталі `m5_cyl.scad`
(вибір користувача), звідти ж їх і читає. Він перевіряє, що вибране влазить і тягне, і
показує, що дали б інші N20 з найкращою для кожного парою шестерень.

  1. ланцюжок довжин: зведена довжина й хід — як у моделі (1:SC), голова вміщується;
  2. сили — з print3d-parts/model_drive.py (віртуальна робота за всіма позами) з масою
     набору, де циліндри набору замінено цими: друковане — з їхніх STL, плюс сталь
     шпильки, гайка, підшипник і мотор, кожне там, де воно справді сидить;
  3. час ходу й навантаження мотора — порожня модель і з повним ковшем піску.

usage: calc.py --kit-stl ТЕКА --own-stl ТЕКА --out CALC.md    # так кличе make.sh
       calc.py --print                                        # теки — за замовчуванням, лише надрукувати
"""
import ast
import glob
import math
import os
import re
import sys

HERE = os.path.dirname(os.path.abspath(__file__))
ROOT = os.path.dirname(os.path.dirname(HERE))
sys.path.insert(0, os.path.join(ROOT, 'print3d-parts'))
import model_drive as md          # noqa: E402  (сам перезапускається через tools/.venv)
import bucket                     # noqa: E402
import kinematics as K            # noqa: E402
from author import md_footer      # noqa: E402


def _arg(name, default=None):
    return sys.argv[sys.argv.index(name) + 1] if name in sys.argv else default


def _first(*dirs):
    """Перша тека, де справді лежать STL (build/ щойно зібраного або latest/)."""
    return next((d for d in dirs if glob.glob(os.path.join(d, '**', '*.stl'), recursive=True)), dirs[0])


KIT_STL = _arg('--kit-stl') or _first(os.path.join(ROOT, 'build', 'print3d', 'stl'), os.path.join(ROOT, 'latest', 'print3d', 'stl'))
OWN_STL = _arg('--own-stl') or _first(os.path.join(ROOT, 'build', 'm5_cylinders', 'stl'),
                                      os.path.join(ROOT, 'latest', 'print3d', 'm5_cylinders', 'stl'))
OUT = None if '--print' in sys.argv else _arg('--out')
md.STL = KIT_STL


def scad_consts():
    """Сталі з m5_cyl.scad — те саме джерело, з якого будуються деталі."""
    src = open(os.path.join(HERE, 'm5_cyl.scad'), encoding='utf-8').read()

    def get(name):
        m = re.search(rf'(?<![\w$]){name}\s*=\s*([^;]+);', src)
        if not m:
            sys.exit(f'calc.py: у m5_cyl.scad немає сталої {name}')
        return ast.literal_eval(m.group(1).strip())
    names = ('SC MOTOR GEAR_M GEAR_ALPHA Z_NUT Z_PIN PISTON PISTON_FIT PUCK REAR_WALL EYE_LEN FRONT_GAP '
             'LIP GAP_SH GEAR_B GAP_F FWALL BRG N20_T').split()
    c = {n: get(n) for n in names}
    c['HEAD_CORE'] = c['LIP'] + c['BRG'][2] + c['GAP_SH'] + c['GEAR_B'] + c['GAP_F'] + c['FWALL']
    return c


C = scad_consts()
Z_PIN_MIN, Z_PIN_MAX = 13, 34   # що перебирати для порівняння; < 17 — з корекцією
A_MAX = 18.0        # мм — далі мотор уже стирчить більше, ніж сама голова
MOTOR_GAP = 0.6     # мм — корпус мотора ↔ гільза
ETA_SPUR = 0.90     # ККД друкованої прямозубої пари з мастилом
SPEED_TOL = 1.10    # пара на 10 % повільніша за найшвидшу, але компактніша — краща
KEYS = ('boom', 'stick', 'bucket')

# маса покупного, г
STEEL_G_PER_MM = 0.154   # шпилька M5 (DIN 976), 1 м ≈ 154 г
N20_G = 10.0             # 12GAN20 з редуктором
BUY_G = 1.1 + 7.0 + 0.3  # ходова гайка M5 (латунна), 698ZZ, магніти й датчики
PISTON_G = 0.9           # поршень — сталева гайка M5 (7.9 під ключ × 4)


def inv(a):
    return math.tan(a) - a


def center_distance(z1, x1, z2, x2):
    """Робоча міжосьова з корекцією — та сама формула, що center_dist() у m5_cyl.scad."""
    a0 = math.radians(C['GEAR_ALPHA'])
    target = 2 * math.tan(a0) * (x1 + x2) / (z1 + z2) + inv(a0)
    lo, hi = 0.0, math.radians(60)
    for _ in range(60):
        mid = (lo + hi) / 2
        lo, hi = (mid, hi) if inv(mid) < target else (lo, mid)
    return C['GEAR_M'] * (z1 + z2) / 2 * math.cos(a0) / math.cos(lo)


def shift(z):
    return round(max(0.0, (17 - z) / 17), 2)


def geometry(sc):
    """Розміри кожного циліндра в друкованих мм і перевірка, що все влазить у зведену довжину."""
    src = open(os.path.join(ROOT, 'scad', 'excavator_boom.scad'), encoding='utf-8').read()
    val = lambda n: float(re.search(rf'^{n}\s*=\s*([\d.]+)\s*;', src, re.M).group(1))
    out = {}
    for i, k in enumerate(KEYS):
        wall = 6.5 if k == 'boom' else 5.0                      # як у hyd_cylinder() моделі
        c = dict(L0=val(f'{k}_cyl_closed') / sc, S=val(f'{k}_cyl_stroke') / sc,
                 od=(val(f'{k}_cyl_bore') + 2 * wall) / sc, pin=val(f'{k}_cyl_pin') / sc,
                 id=C['PISTON'][0] + 2 * C['PISTON_FIT'])            # канал — шестигранник, під ключ
        c['x_ci'] = C['EYE_LEN'] + C['REAR_WALL']                # дно кришки: упор поршня у зведеному
        c['x_hr'] = c['x_ci'] + c['S'] + C['PUCK']              # задній торець голови: упор у розкритому
        c['nose'] = c['L0'] - C['EYE_LEN'] - C['FRONT_GAP'] - c['x_hr'] - C['HEAD_CORE']
        c['screw'] = c['L0'] - c['pin'] / 2 - 0.8 - c['x_ci']  # хвіст у поршні → кінець у вушку
        c['a_min'] = c['od'] / 2 + C['N20_T'] / 2 + MOTOR_GAP
        if c['nose'] < 0:
            sys.exit(f'calc.py: {k}: голова не влазить у зведену довжину (бракує {-c["nose"]:.1f} мм)')
        out[k] = c
    return out


def gear_pairs(a_min):
    """[(z_pin, x_pin, a, i)] — пари, що стають: мотор не ближче a_min до гільзи і не далі A_MAX."""
    res = []
    for zp in range(Z_PIN_MIN, Z_PIN_MAX + 1):
        a = center_distance(C['Z_NUT'], 0.0, zp, shift(zp))
        if a_min <= a <= A_MAX:
            res.append((zp, shift(zp), a, C['Z_NUT'] / zp))
    return res


def own_mass():
    """Друковані деталі циліндрів, г: {(циліндр, 'body'|'rod'): маса} з їхніх STL."""
    out = {}
    for f in glob.glob(os.path.join(OWN_STL, '*.stl')):
        m = re.match(r'(boom|stick|bucket)_(\w+)_x(\d+)\.stl$', os.path.basename(f))
        if m:
            k, part, qty = m.group(1), m.group(2), int(m.group(3))
            side = 'rod' if part == 'eye' else 'body'
            out[k, side] = out.get((k, side), 0.0) + md.stl_volume(f) * qty * md.PLA * md.FILL
    if len(out) < 2 * len(KEYS):
        sys.exit(f'calc.py: немає STL циліндрів у {OWN_STL} — спершу make.sh stl')
    return out


def main():
    md.check_cylinders()
    sc = md.scale()
    if sc != C['SC']:
        sys.exit(f'calc.py: SC у m5_cyl.scad = {C["SC"]}, у parts.scad = {sc}')
    g = K.GEOM
    geo = geometry(sc)
    printed = own_mass()

    # --- маса й центр ваги кожного циліндра (відстані в мм МАШИНИ від пальця бази / штока)
    ends = dict(boom=('C', 'D'), stick=('F', 'G'), bucket=('H', 'J'))
    cyl_load, cyl_rows = [], []
    for k, c in geo.items():
        body_p, rod_p = printed[k, 'body'], printed[k, 'rod']
        head_x = c['x_hr'] + 6                                    # мотор, гайка, підшипник
        body_m = body_p + N20_G + BUY_G
        body_x = (body_p * c['L0'] * 0.55 + (N20_G + BUY_G) * head_x) / body_m
        steel = c['screw'] * STEEL_G_PER_MM + PISTON_G
        rod_back = c['L0'] - (c['x_ci'] + c['screw'] / 2)         # від пальця штока — не міняється з ходом
        p1, p2 = ends[k]
        cyl_load += [(body_m, ('ax', p1, p2, body_x * sc)), (rod_p + steel, ('axr', p1, p2, rod_back * sc))]
        cyl_rows.append((k, body_p, rod_p, steel, body_m + rod_p + steel))

    orig_locate = md.locate

    def locate(p, where):
        """Точка на осі циліндра: 'ax' — d мм від першої точки, 'axr' — від другої."""
        if isinstance(where, tuple) and where[0] in ('ax', 'axr'):
            _, a, b, d = where
            A, B = (p[a], p[b]) if where[0] == 'ax' else (p[b], p[a])
            return K.add(A, K.mul(K.sub(B, A), d / K.dist(A, B)))
        return orig_locate(p, where)
    md.locate = locate

    parts = [(m, w) for key, m, w in md.masses() if w is not None and not key.startswith('cyl_')]
    pr = bucket.profile(bucket.BUCKET, g)
    cap = bucket.capacity(bucket.BUCKET, g)
    sand_g = cap['heaped'] * 1000 / sc ** 3 * md.SAND
    bk_pts = {'bk': tuple(pr['side'].centroid.coords[0]), 'sand': tuple(pr['struck'].centroid.coords[0])}
    load = parts + cyl_load
    F_empty = md.forces(g, load, bk_pts)
    F_sand = md.forces(g, load + [(sand_g, 'sand')], bk_pts)
    T_empty, T_sand = md.torques(F_empty, 0.0), md.torques(F_sand, 0.0)   # підшипник — торця немає

    q = md.Q_LPM * 1e6 / 60
    real = {k: (c['stroke'] / (q / c['A_push']), c['stroke'] / (q / c['A_pull'])) for k, c in K.CYL.items()}
    turns = {k: geo[k]['S'] / md.PITCH for k in geo}
    every = {(r, n0): (md.n20_stall(r, n0, i0, ist), ds * 98.07, rated * 98.07, ist)
             for r, n0, i0, _, _, rated, ds, ist in md.N20}

    def run(k, n0, ts, i, T):
        """(час висування, втягування, частка моменту зупинки мотора) або None — стоїть."""
        tm = [T[k, s] / (i * ETA_SPUR) for s in (0, 1)]
        if max(tm) >= ts:
            return None
        t = [turns[k] / (n0 / i * (1 - tm[s] / ts) / 60) for s in (0, 1)]
        return t[0], t[1], max(tm) / ts

    # --- вибране
    R, N0 = C['MOTOR']
    if (R, N0) not in every:
        sys.exit(f'calc.py: 12GAN20-{R}, {N0} об/хв немає в каталозі model_drive.N20')
    TS, TS_DS, T_RATED, IST = every[R, N0]
    pick = {}
    for i, k in enumerate(KEYS):
        zp = C['Z_PIN'][i]
        a = center_distance(C['Z_NUT'], 0.0, zp, shift(zp))
        res = run(k, N0, TS, C['Z_NUT'] / zp, T_empty)
        if a < geo[k]['a_min'] or a > A_MAX:
            sys.exit(f'calc.py: {k}: пара {C["Z_NUT"]}/{zp} (a = {a:.2f}) не стає: треба {geo[k]["a_min"]:.1f}…{A_MAX:g} мм')
        if res is None:
            sys.exit(f'calc.py: {k}: 12GAN20-{R}, {N0} об/хв з парою {C["Z_NUT"]}/{zp} не тягне порожню модель')
        pick[k] = (a, zp, C['Z_NUT'] / zp, res)

    # --- порівняння: кожен N20 з найкращою парою на кожен циліндр
    pairs = {k: gear_pairs(c['a_min']) for k, c in geo.items()}
    best = {}
    for (r, n0), (ts, _, _, ist) in every.items():
        if ist == 1.0 and (r, n0) != (R, N0):
            continue                                          # рядки з «заглушкою» струму — не порівнюємо
        for k in geo:
            cand = []
            for zp, xp, a, i in pairs[k]:
                res = run(k, n0, ts, i, T_empty)
                if res and res[2] <= md.OVERLOAD:
                    cand.append((max(res[0] / real[k][0], res[1] / real[k][1]), a, zp, i, res))
            if cand:
                top = max(1.0, min(cand)[0]) * SPEED_TOL
                best[r, n0, k] = min((c for c in cand if c[0] <= top), key=lambda c: c[1])
    ranked = sorted((max(best[r, n0, k][0] for k in geo), r, n0) for (r, n0) in every
                    if all((r, n0, k) in best for k in geo))

    L = []
    w = L.append
    w('# Циліндри M5 — розрахунок')
    w('')
    w('> Згенеровано `print3d-parts/m5_cylinders/calc.py` (крок `make.sh`) — руками не правити. '
      'Як влаштовано й навіщо — `print3d-parts/m5_cylinders/README.md`.')
    w('')
    w(f'## Довжини (друковані мм, 1:{sc})')
    w('')
    w('Зведена довжина й хід — ті самі, що в моделі. Упори — поршень (сталева гайка) об дно кришки (зведений) і об задній '
      'торець голови (розкритий); шийка вушка штока голови не торкається.')
    w('')
    w('| Циліндр | Зведений | Хід | Розкритий | Гільза: Ø зовн. / канал під ключ | Дно кришки | Голова від | Запас на ніс | Шпилька M5 |')
    w('|---|---:|---:|---:|---|---:|---:|---:|---:|')
    for k, c in geo.items():
        w(f'| {md.NAMES[k]} | {c["L0"]:.0f} | {c["S"]:.0f} | {c["L0"] + c["S"]:.0f} | {c["od"]:.1f} / {c["id"]:.1f} | '
          f'{c["x_ci"]:.1f} | {c["x_hr"]:.1f} | {c["nose"]:.1f} | {c["screw"]:.0f} |')
    w('')
    w(f'«Дно кришки» й «голова від» — від осі пальця бази. Голова займає {C["HEAD_CORE"]:.1f} мм; що лишилось '
      '(«запас на ніс») — напрямна шпильки попереду голови.')
    w('')
    w('## Маса циліндрів')
    w('')
    w('| Циліндр | Друковане: корпус, г | Друковане: шток, г | Шпилька, г | Разом з мотором, г |')
    w('|---|---:|---:|---:|---:|')
    for k, bp, rp, st, tot in cyl_rows:
        w(f'| {md.NAMES[k]} | {bp:.1f} | {rp:.1f} | {st:.1f} | {tot:.1f} |')
    w('')
    w(f'Друковане — з STL циліндрів, PLA {md.PLA} г/см³, 100 %. Мотор {N20_G:g} г і гайка з підшипником сидять '
      'у голові; сталь шпильки важить приблизно як уся друкована гільза. Решта машини — з STL набору.')
    w('')
    w('## Вибраний мотор')
    w('')
    w(f'**12GAN20-{R}, {N0} об/хв**, шестерні ' + ', '.join(
        f'{md.NAMES[k].lower()} {C["Z_NUT"]}/{pick[k][1]}' for k in KEYS) +
      f', міжосьова {pick["boom"][0]:.2f} мм. Час ходу моделі (висування / втягування) і частка моменту зупинки мотора:')
    w('')
    w('| Циліндр | Машина, с | Модель порожня, с | Модель з піском, с | Повільніше за машину |')
    w('|---|---:|---:|---:|---:|')
    for k in KEYS:
        a, zp, i, (te, tr, ld) = pick[k]
        rs = run(k, N0, TS, i, T_sand)
        slow = max(te / real[k][0], tr / real[k][1])
        w(f'| {md.NAMES[k]} | {real[k][0]:.1f} / {real[k][1]:.1f} | {te:.0f} / {tr:.0f} · {ld * 100:.1f} % | ' +
          ('стоїть' if rs is None else f'{rs[0]:.0f} / {rs[1]:.0f} · {rs[2] * 100:.1f} %') + f' | ×{slow:.0f} |')
    lam = math.atan(md.PITCH / (math.pi * md.D2))
    phi = math.atan(md.MU_THREAD / math.cos(math.radians(30)))
    kf = md.D2 / 2 * math.tan(lam + phi)                    # Н·мм на Н осьової сили
    w('')
    w('Сила ваги на циліндрах, Н (порожня / з піском, штовхає / тягне): ' + '; '.join(
        f'{md.NAMES[k].lower()} {F_empty[k][0]:.1f}/{F_empty[k][1]:.1f} · {F_sand[k][0]:.1f}/{F_sand[k][1]:.1f}'
        for k in KEYS) + '.')
    w('')
    w(f'**Упори.** Номінальний момент з даташиту ({T_RATED:.0f} Н·мм) дає на шпильці ≈ {T_RATED * ETA_SPUR / kf:.0f} Н, '
      f'момент зупинки ({min(TS, TS_DS):.0f}–{max(TS, TS_DS):.0f} Н·мм) — ≈ {min(TS, TS_DS) * ETA_SPUR / kf:.0f} Н'
      + (' (струм зупинки в даташиті — «заглушка» 1.00 А)' if IST == 1.0 else '') +
      f'. Вага ж — не більше {max(max(F_sand[k]) for k in KEYS):.0f} Н. Друковані упори (698ZZ осьово тримає ≈ 400 Н) '
      'розраховані на вагу, а не на мотор: зупиняють датчики кінцевиків, драйвер обмежує струм.')
    w('')
    w('## Що дали б інші N20')
    w('')
    w(f'Шестерня гайки z = {C["Z_NUT"]} (менша не вміщає гайку й магніти), модуль {C["GEAR_M"]}. Мотор не ближче '
      f'{MOTOR_GAP} мм до гільзи й не далі {A_MAX:g} мм від осі, тож прискорити гайку шестернями майже нікуди '
      f'(i ≥ {C["Z_NUT"] / Z_PIN_MAX:.2f}) — швидкість задає сам мотор. ККД пари {ETA_SPUR}. Кожен мотор — з '
      f'найкомпактнішою парою, не повільнішою за найшвидшу більш ніж на {SPEED_TOL * 100 - 100:.0f} %, і лише без '
      f'перегріву (≤ {md.OVERLOAD * 100:.0f} % моменту зупинки) на порожній моделі.')
    w('')
    w('| Мотор | Стріла | Рукоять | Ківш | Повільніше за машину |')
    w('|---|---|---|---|---:|')
    for worst, r, n0 in ranked:
        cells = [f'{C["Z_NUT"]}/{best[r, n0, k][2]}: {best[r, n0, k][4][0]:.1f} / {best[r, n0, k][4][1]:.1f} с · '
                 f'{best[r, n0, k][4][2] * 100:.0f} %' for k in KEYS]
        mark = ' ← вибрано' if (r, n0) == (R, N0) else ''
        w(f'| 12GAN20-{r}, {n0} об/хв{mark} | ' + ' | '.join(cells) + f' | ×{worst:.1f} |')
    w('')
    w('Машина: ' + ', '.join(f'{md.NAMES[k].lower()} {real[k][0]:.1f} / {real[k][1]:.1f} с' for k in KEYS) +
      ' (висування / втягування, весь потік насоса в один циліндр).')
    w('')
    w(md_footer())
    text = '\n'.join(L) + '\n'
    if OUT is None:
        print(text)
        return
    open(OUT, 'w', encoding='utf-8').write(text)
    print(f'  {os.path.relpath(OUT, ROOT)} — мотор 12GAN20-{R}, {N0} об/хв; стріла ' +
          f'{pick["boom"][3][0]:.0f} с на хід')


if __name__ == '__main__':
    main()

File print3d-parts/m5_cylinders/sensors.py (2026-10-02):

#!/usr/bin/env python3
"""Як ставити датчики Холла в циліндр M5 → SENSORS.svg (однаково для стріли, рукояті й ковша).

Корпус SS41F / SS49E, куди дивиться сторона з маркуванням, куди йдуть ніжки й де який вивід,
якщо дивитися з того боку, з якого датчик вставляється в гніздо. Розташування — з m5_cyl.scad:
латчі енкодера під PHI+90° і PHI+180°, кінцевики під PHI+180° (PHI — напрямок на мотор).
Чистий Python без залежностей (make.sh кличе його системним python3).

usage: sensors.py [--out SENSORS.svg]
"""
import argparse
import math
import os
import re
import sys
from xml.sax.saxutils import escape

HERE = os.path.dirname(os.path.abspath(__file__))
sys.path.insert(0, os.path.join(os.path.dirname(os.path.dirname(HERE)), 'tools'))
from author import line as author_line  # noqa: E402

W, H = 1200, 1010
FONT = 'DejaVu Sans, Arial, sans-serif'
INK, GREY, BOX = '#212121', '#616161', '#fafafa'
C_BODY, C_MARK, C_MAG_N, C_MAG_S = '#263238', '#ffca28', '#c62828', '#1565c0'
C_PLA, C_HEAD, C_LEAD = '#cfd8dc', '#90caf9', '#9e9e9e'
PIN_FRONT = ('VS', 'GND', 'OUT')   # сторона з маркуванням до себе, ніжки донизу: зліва направо
PIN_C = {'VS': '#c62828', 'GND': '#37474f', 'OUT': '#2e7d32'}

out = []


def scad_consts():
    src = open(os.path.join(HERE, 'm5_cyl.scad'), encoding='utf-8').read()

    def num(name):
        m = re.search(rf'^{name}\s*=\s*([\d.]+)\s*;', src, re.M)
        if not m:
            sys.exit(f'sensors.py: у m5_cyl.scad немає сталої {name}')
        return float(m.group(1))
    return {'R_MAG': num('R_MAG'), 
        'ENC': re.search(r'^ENC_ANG\s*=\s*\[PHI \+ (\d+), PHI \+ (\d+)\]', src, re.M).groups(),
        'SENS': re.search(r'^PHI_SENS\s*=\s*PHI \+ (\d+)', src, re.M).group(1)}


def ln(x1, y1, x2, y2, c=INK, w=2, dash=None):
    d = f' stroke-dasharray="{dash}"' if dash else ''
    out.append(f'<line x1="{x1:.1f}" y1="{y1:.1f}" x2="{x2:.1f}" y2="{y2:.1f}" stroke="{c}" stroke-width="{w}"{d}/>')


def tx(x, y, s, size=12, anchor='start', weight='normal', c=INK):
    out.append(f'<text x="{x:.1f}" y="{y:.1f}" font-size="{size}" text-anchor="{anchor}" font-weight="{weight}" '
               f'fill="{c}">{escape(s)}</text>')


def rect(x, y, w, h, fill=BOX, c=INK, rx=0, sw=1.5, dash=None):
    d = f' stroke-dasharray="{dash}"' if dash else ''
    out.append(f'<rect x="{x:.1f}" y="{y:.1f}" width="{w:.1f}" height="{h:.1f}" rx="{rx}" fill="{fill}" '
               f'stroke="{c}" stroke-width="{sw}"{d}/>')


def circ(x, y, r, fill=BOX, c=INK, sw=1.5, dash=None):
    d = f' stroke-dasharray="{dash}"' if dash else ''
    out.append(f'<circle cx="{x:.1f}" cy="{y:.1f}" r="{r:.1f}" fill="{fill}" stroke="{c}" stroke-width="{sw}"{d}/>')


def arrow(x1, y1, x2, y2, c=INK, w=2):
    ln(x1, y1, x2, y2, c, w)
    a = math.atan2(y2 - y1, x2 - x1)
    pts = [(x2, y2), (x2 - 10 * math.cos(a - 0.4), y2 - 10 * math.sin(a - 0.4)),
           (x2 - 10 * math.cos(a + 0.4), y2 - 10 * math.sin(a + 0.4))]
    out.append(f'<polygon points="{" ".join(f"{p:.1f},{q:.1f}" for p, q in pts)}" fill="{c}"/>')


def sensor(cx, cy, leads, face, label='', k=10.0):
    """Датчик у пласкому TO-92 (4.1×3.0 мм), вид на одну зі сторін.

    leads: куди йдуть ніжки — 'down' | 'left' | 'up' | 'right'; face: 'front' (маркування до нас) |
    'back' (маркування від нас, як видно з боку вставляння). k — пікселів на мм."""
    rot = {'down': 0, 'left': 90, 'up': 180, 'right': 270}[leads]
    ca, sa = math.cos(math.radians(rot)), math.sin(math.radians(rot))

    def p(x, y):   # локально: ніжки вздовж +y (донизу в SVG), поворот за годинниковою стрілкою
        return cx + (x * ca - y * sa) * k, cy + (x * sa + y * ca) * k
    body = [p(-2.05, -1.5), p(2.05, -1.5), p(2.05, 1.5), p(-2.05, 1.5)]
    fill = C_BODY if face == 'front' else '#546e7a'
    out.append(f'<polygon points="{" ".join(f"{a:.1f},{b:.1f}" for a, b in body)}" fill="{fill}" '
               f'stroke="{INK}" stroke-width="1.5"/>')
    names = PIN_FRONT if face == 'front' else PIN_FRONT[::-1]
    for i, name in enumerate(names):
        x = (i - 1) * 1.27
        c = PIN_C[name]
        (x1, y1), (x2, y2) = p(x, 1.5), p(x, 4.2)
        ln(x1, y1, x2, y2, c, 2.5)
        lx, ly = p(x, 5.2 + (1.1 if i == 1 and leads in ('up', 'down') else 0) * 10 / k)   # середній — нижче
        tx(lx, ly + 4, name, 10, 'middle', 'bold', c)
    mx, my = p(0, 0)
    if face == 'front':
        tx(mx, my + 4, label, 10, 'middle', 'bold', C_MARK)
    else:
        tx(mx, my + 4, 'зворот', 9, 'middle', c='#eceff1')


def svg(path):
    C = scad_consts()
    out.clear()
    out.append(f'<svg xmlns="http://www.w3.org/2000/svg" width="{W}" height="{H}" viewBox="0 0 {W} {H}" '
               f'font-family="{FONT}">')
    out.append(f'<rect width="{W}" height="{H}" fill="white"/>')
    tx(40, 40, 'Циліндр M5 · датчики Холла: де стоять і як повернуті', 18, weight='bold')
    tx(40, 62, 'однаково для стріли, рукояті й ковша; усі гнізда відкриті назовні — датчики вставляються після друку', 12,
       c=GREY)

    # ---------------- 1. корпус
    rect(30, 84, 360, 330, rx=6)
    tx(46, 108, '1. Корпус SS41F і SS49E (пласкі TO-92)', 13, weight='bold')
    sensor(120, 170, 'down', 'front', '41F', 16)
    tx(120, 310, 'сторона з маркуванням', 11, 'middle'); tx(120, 325, 'до себе, ніжки донизу', 11, 'middle')
    sensor(290, 170, 'down', 'back', k=16)
    tx(290, 310, 'та сама, зі звороту', 11, 'middle'); tx(290, 325, '(як видно при вставлянні)', 11, 'middle')
    notes = ['Чутливий елемент — ближче до сторони з маркуванням;',
             'поле має входити в неї поперек корпусу.',
             'Тому маркування — завжди до магніту.',
             'Виводи в обох датчиків однакові: VS · GND · OUT.']
    for i, s in enumerate(notes):
        tx(46, 350 + 16 * i, s, 11, c='#424242')
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

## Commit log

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2026-09-20 V001: перша повна версія — модель, ківш, креслення, двомовна 3D-сторінка
    versions/V001-2026-09-20-0359/: STL 23 вузлів, 11 рендерів, звіти
    кінематики, міцності та ковша, специфікація (bom.md, bom.csv), 12 DXF
    1:1, 18 сторінок ескізів у PDF, viewer.html і знімок моделі зі
    скриптами. Маса робочого обладнання 130.2 кг без циліндрів і колони.
    Перевірки на момент збирання: перекриттів пластин немає; рухомі пари
    не зіткаються на всьо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
    [A_doubler.dxf, B_fork.dxf, D_clevis.dxf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]
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2026-09-20 Застереження там, де його реально побачать, і SAFETY.md
    README читає не кожен: креслення друкують і несуть у цех різання,
    звіти відкривають окремо, 3D-сторінку можна викласти на GitHub Pages,
    де README немає взагалі. Тому застереження тепер ще й:
    - у підвалі КОЖНОГО аркуша parts.pdf і сторінок png/;
    - у шапці bom.md і першим рядком bom.csv;
    - у панелі обох 3D-сторінок (у WASM-версії — обома мовами, ключ warn);
    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
    [A_doubler.dxf, B_fork.dxf, D_clevis.dxf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]
2026-09-20 Рушій viewer-wasm: openscad-wasm-prebuilt замість openscad-wasm
    Заміна зроблена заради можливості виконати GPL. Старий пакет
    openscad-wasm@0.0.4 не містив ні файлу ліцензії, ні repository, ні
    homepage — встановити, з якого коду зібрано бінарник, було неможливо,
    а отже неможливо виконати §3 GPL при публікації dist/.
    openscad-wasm-prebuilt@1.2.0 містить повний текст GPL-2.0 (покладено
    в tools/viewer-wasm/LICENSE, md5 b234ee4d69f5fce4486a80fdaf4a4263) і
    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
    [A_doubler.dxf, B_fork.dxf, D_clevis.dxf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]
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2026-09-20 Друкований набір 1:7: STL усіх деталей, перевірка друкованості, BOM
    Модель не змінена: print_parts.scad підключає scad/excavator_boom.scad як
    бібліотеку з part="none" і збирає деталі з її ж модулів.
    Масштаб 1:7 — найбільший цілий, за якого стріла (1674.7 мм) влазить у стіл
    250 мм: 239.2 мм. 1:6 дав би 279 мм.
    30 деталей: колона ×2, стріла, рукоять, ківш, коромисло ×2, тяга ×2, три
    циліндри (гільза + шток), 4 втулки, 11 пальців.
    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
    [01_post_plate_x2.stl, 02_boom_x1.stl, 03_stick_x1.stl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]
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2026-09-20 Друкований набір компонентів під зварювання 1:5 (print3d-parts/)
    Другий розріз тієї самої моделі: не зварні вузли, як у print3d/, а КОЖЕН
    компонент окремо — так, як його ріжуть з металу. 53 файли, 76 штук:
    3 профільні труби, 19 пластин, накладок, сідел і ребер, обичайка ковша, ніж,
    зуби, смуги зносу, 10 втулок і бобишок, 11 пальців, 3 робочі циліндри.
    Масштаб перерахований, бо найбільша деталь інша: не стрі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
    [01_tube_boom_seg1_x1.stl, 02_tube_boom_seg2_x1.stl, 03_tube_stick_x1.stl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]
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2026-09-21 Інструкція складання, ескізи в BOM, виправлений палець C, підрізка рендерів
    print3d-parts/ASSEMBLY.md: 53 кроки в семи розділах — що до чого приклеюється,
    з габаритом кожної деталі. Порядок з'єднань у assembly.tsv (пишеться руками),
    усі числа з parts.tsv і ВИМІРЯНИХ STL. make.sh зупиняється, якщо деталь набору
    лишилася без кроку складання.
    Таблиця «як не сплутати» рахується, а не пишеться: пари, де всі три габарит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
    [18_pin_C_x1.stl, 44_pin_C_x1.stl, assembly.tsv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]
2026-09-21 Креслення прив'язок вежі F і вилки D; відкочено хибне виправлення пальця C
    print3d-parts/img/positions.png: вид збоку і переріз для двох деталей, що стають
    ПОСЕРЕД пластини, не впираючись ні в кромку, ні в отвір. Контури справжні —
    з моделі через projection(cut=true), як в ескізах пластин; розміри з того самого
    echo(POS), що й таблиця в ASSEMBLY.md, тож розійтися вони не можуть. Види
    розвернуто по деталі (сегмент і вісь к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
    [18_pin_C_x1.stl, 44_pin_C_x1.stl, assembly.tsv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]
2026-09-21 Прив'язки: усі чотири накладні деталі, числа обміром, коди на кресленні
    Було дві деталі з чотирьох. Додано 13_H_clevis і 22_bk_ear — той самий клас:
    приварюються посеред пластини, не впираючись ні в кромку, ні в отвір. Вилка H
    найважливіша: вона стоїть НЕСИМЕТРИЧНО (2 мм ззаду, 12 спереду), тобто «на око
    по центру» гарантовано неправильно, і помилка на 10 мм не кидається в очі.
    Числа більше не вписа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
    [assembly.tsv, parts.scad, pos_cut.scad]
2026-09-21 Крупні плани кріплень, --render обов'язковий, економія на перевірці картинок
    ДРУГИЙ РАКУРС кожного вузла в ASSEMBLY.md: на загальному виді вуха ковша, вежа F
    і вилка D ховаються за корпусом, а саме їх найважче поставити правильно.
    --render У КОЖНОМУ РЕНДЕРІ. Без нього OpenSCAD малює прев'ю (OpenCSG), а в прев'ю
    поверхні деталей, що ДОТИКАЮТЬСЯ, пробивають одна одну: труба малювалася поверх
    накладки перело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
    [pos_cut.scad]
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2026-09-21 Попередження про ШІ — під значком ⚠ у ручці шухляди
    - кнопки мови в ручці ставали 40 px від правила «#side button» і налазили
    на рядок попередження; тепер вони 23 px, а ⚠ стоїть ліворуч у ручці
    - сам текст показується карткою position: fixed поверх моделі: у панелі
    його обрізало б прокруткою. Дотик по картці закриває, шухляда при цьому
    не рухається
    - на великому екрані все як було: значка немає, поп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
2026-09-23 CLAUDE.md: environment facts and two more shell traps
    What tools/.venv has and what the system python must stay without, where
    Chrome, node+puppeteer-core and OpenSCAD are, and that there is no pdftoppm,
    mutool, gs or ImageMagick — so a session does not probe for them again. Plus
    the zsh '=word' expansion trap and the IDE spell-checker noise on Cyrillic.
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2026-09-23 Shared STL and callout libraries in tools/; render cache keyed by part order
    tools/stl_mesh.py: binary STL reader with an ASCII guard, largest planar face,
    silhouette via shapely, circle fit. tools/hue_callouts.py: pixel-hue
    classification, anchors, background/edge finishing, label spreading, and a
    PIL callout drawer for publication images. make_sheets.py now imports both
    instead of carrying its own copies; sheets.json is byte-identical after a
    full re-render (only the render counter differs).
    Found while testing: the render cache name did not include the key list, so
    reordering assembly.tsv would silently swap the callouts on cached renders.
    The cache name now carries a hash of the key lis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
2026-09-23 media-kit: headless OpenSCAD render recipe and hue-based callouts
    The flags that work (--preview keeps color(), Tomorrow background, gimbal
    camera, close-ups without --viewall), what does not (--view=edges, silent
    crashes), and the callout technique now shared in tools/hue_callouts.py.
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2026-09-24 README for a first-time visitor; technical detail moves to TECHNICAL.md
    - README (en/uk): a short AI warning under the title, then the live 3D model
    link with an animated tour of the page, the three PDFs with page previews,
    what this is with the headline numbers, the printed kit, the full disclaimer
    and the licence.
    - TECHNICAL.md / TECHNICAL.uk.md: sections 1-6 of the old README verbatim,
    next stages as section 7; SAFETY, QUICKSTART and project rules point there.
    - tools/media/readme_media.sh: page tour GIFs in both languages
    (page_tour.mjs) and PDF previews (pdf_preview.py) into docs/img/.
    - build_version.sh rewrites the README links to the latest version's
    sketches and DXF.
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2026-09-24 Tooling for the chores that kept repeating
    - print3d-parts/stl_same.py, last step of make.sh: STL files whose triangle set
    matches the index (only the order changed) are restored, so only real
    geometry changes reach a commit.
    - Sheet render cache keyed by a hash of the model, logo polygons and wrappers:
    a stale render after a model change is no longer possible, no --fresh needed.
    - tools/check_personal.py: staged changes scanned for personal data, including
    PDF text/metadata, PNG text chunks and zip-based files like .3mf; the
    machine-specific patterns are read at run time.
    - tools/check_docs.py: links, anchors and the skeleton of the en/uk twins.
    - npm test warns when the WASM mode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
2026-09-24 Stand folder: snap-on clip that locks a printed cylinder rod in both directions
    One clip per cylinder size (boom; stick and bucket). A stepped C-clip snaps
    from below onto the bare rod and the end of the barrel at once: a hole in
    the barrel sleeve captures the oil-port boss, so the clip is locked on the
    barrel; the step face stops retraction; the rod sleeve holds extension by
    friction. Sizes come from the model; make.sh checks that the clip clears
    the barrel and rod and that the boss sits in the hole.
    [clip_boom.stl, clip_stick_bucket.stl, stand.scad]
2026-09-25 Stand clip: wider wrap on the rod sleeve, interference fit
    The rounded jaw tips ate ~9 deg of wrap per side, so a 225 deg rod sleeve
    held the rod only ~207 deg and it slipped out through the gap. The rod
    sleeve now has its own CLIP_ROD_ARC = 245 (~227 deg effective); the body
    sleeve and the thick transition stay at 225. CLIP_FIT = -0.15 for a press
    fit. The clip placement checks in make.sh run at nominal fit, since the
    intended interference would otherwise show up as an overlap.
    [clip_boom.stl, clip_stick_bucket.stl, stand.scad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]
2026-09-25 Stand clip: separate rod-sleeve fit per clip, wider rod wrap
    With the same 1.6 mm wall, the sleeve on the 8 mm boom rod clamps about
    three times weaker than on the 5 mm rod (ring stiffness ~1/R^3), and the
    boom cylinder carries the most load. New CLIP_ROD_FIT = [-0.4, -0.2]
    (boom / stick and bucket); CLIP_FIT now applies only to the body sleeve,
    which the oil port already locks. Rod wrap raised to 260 deg.
    clip_step() now accounts for both fits, so the transition cone stays at
    exactly 45 deg and does not print as an overhang. The make.sh placement
    checks zero both fits.
    [clip_boom.stl, clip_stick_bucket.stl, stand.scad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]
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2026-09-29 WASM page AR: depth occlusion, room planes and mesh, collision warnings
    The AR session now asks for depth-sensing, plane-detection and mesh-detection as optional features and uses whichever the browser grants. Real depth hides the machine behind real objects; detected planes and the room mesh are drawn semi-transparent; each body is checked against them ten times a second and hits are shown in red with a warning banner. Overlay buttons toggle occlusion, the room display and collision checking. Collision geometry lives in src/room.js and is covered by npm test; __ARSIM__ checks the real model against a synthetic wall.
2026-09-29 WASM page AR: room snapshot and room scan from depth maps
    Planes the browser loses now stay as ghosts; a plane that reappears or is large and long-seen is kept for the session, and the depth map removes a kept plane it sees through. Ghosts take part in collisions (src/keep.js).
    The new scan button fuses depth frames into a 3D model of the room: a sparse TSDF voxel grid with free-space carving, meshed with Surface Nets and drawn in 1.6 m chunks, shaded with smooth normals from the field, ambient occlusion and a camera-facing term. An opacity slider goes from see-through to solid (src/scan.js).
    The AR hint moves to its own row so five buttons fit on a phone. TECHNICAL gains a colour legend f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
2026-09-29 WASM page: SpaceMouse drives the bucket while the camera is locked
    Push/pull moves the tooth forward/back, press/lift down/up, tilt curls or
    dumps; boom, stick and bucket are solved together so the bucket keeps its
    angle (armFromBucket). Reference frame switch: from the base or from the
    camera. Shared spacemouse block gets an SM.arm hook in both pages.
    Tests: IK round trip in smoke, bucket mode in spacemouse.mjs.
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2026-09-29 Print kit: N20 gearmotor catalogue and per-cylinder fit in the M5 drive section
    model_drive.py now lists the 12GAN20 12 V variants from the supplier
    datasheet and recomputes stall torque from current (T = eta*U*(I_stall -
    I_noload)/w0), since the datasheet kg*cm figures imply efficiency above
    100 %. For each cylinder and candidate motor (direct drive on the nut) it
    gives loaded stroke times and share of stall torque, empty and with a full
    bucket of sand, with and without a thrust bearing; the recommendation is
    generated from the same tables.
2026-09-29 Move the pages to web/ and dev helpers to tools/dev/
    The pages are the published product, not build tools: web/viewer-wasm
    (GitHub Pages), web/viewer with its server viewer.py, and their launchers.
    The SpaceMouse helper and agent analytics go to tools/dev/. Python tools
    stay flat in tools/: calc, drawings and the print kit import each other.
    - relative paths fixed: package.json dev:sm, viewer.py page, analytics root
    - paths updated in CLAUDE.md, skills, pages.yml, bilingual docs, model comments
    [excavator_boom.scad]
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2026-09-29 Twin check, page docs in web/README, linters, stable README drawing images
    - tools/check_twins.py: kinematics.py and bucket.py against the model
    (parameters, joint points in 27 poses, angle ranges, bucket profile) in one
    OpenSCAD run; stops build_version.sh and the pre-commit hook on divergence
    - web/README(.uk).md: the 3D page docs moved out of TECHNICAL; the file table
    of TECHNICAL section 1 moved to ARCHITECTURE section 7
    - CLAUDE.md: page rules condensed, details now in the browser-verify and
    web-safety skills; print-kit skill points to the kit README
    - tools/requirements*.txt, ruff.toml, .shellcheckrc, tools/lint.sh; lint fixes;
    install into the venv with python -m pip (bin/pi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
    [calc.py]
2026-09-29 Print kit: piston magnet unified to Ø2×1 in M5 cylinders
    The end-stop magnet is now the same Ø2×1 disc as the encoder ones, so the
    cylinders need one magnet size. DRV5032 (≤4.8 mT) still sees 11–27 mT at the
    stop; the documented trigger distance is corrected to ~2–3 mm.
    [m5_cyl.scad]
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2026-09-29 Print kit: per-part visibility checkboxes in the M5 cylinder model
    A Customizer group "Що показати" toggles each part of the assembly and the
    section views, so the inside can be inspected; it replaces show_buy. The
    make.sh checks use the parts directly and are unaffected; default renders
    match the kit.
    [m5_cyl.scad]
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2026-10-02 Print kit V006.2: M5 cylinders reworked, sensors drawing (sensors.py), glued gear hubs
    [01_tube_boom_seg1_x1.stl, 02_tube_boom_seg2_x1.stl, 03_tube_stick_x1.stl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]
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2026-10-19 docs(technical): credit the half-thickness plate shift to the author
    The list of fixes after the four-agent review included "every plate
    in the model shifted by half its thickness", which read as one of the
    agents' findings. The author noticed it, not the agents. It is now a
    separate sentence at the end of the same paragraph, in both language
    twins, so the structure of the bilingual pair stays identical.
